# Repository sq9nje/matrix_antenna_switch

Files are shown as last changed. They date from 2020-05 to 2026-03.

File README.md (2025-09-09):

# 6x2 Matrix Antenna Switch

A complete antenna switching system that allows connecting two transceivers to up to 6 antennas with intelligent control and protection.

## Overview

This project implements a 6x2 matrix antenna switch system consisting of two main modules:

- **Relay Module**: High-power RF switching matrix with electromechanical relays
- **Interface Module**: ESP32-based control system with RS485 communication

The system provides flexible antenna routing while preventing simultaneous connection of both transceivers to the same antenna, ensuring equipment protection and operational safety.

## Key Features

### RF Performance
- **Power Handling**: Up to 1.5kW (full amateur license power)
- **Frequency Range**: DC to 50+ MHz with good performance
- **Protection**: Gas discharge tubes on all antenna ports for lightning/ESD protection
- **Isolation**: Decent port-to-port isolation
  - Better than 75dB below 10MHz
  - Better than 65dB below 30MHz
  - Better than 50dB below 50MHz
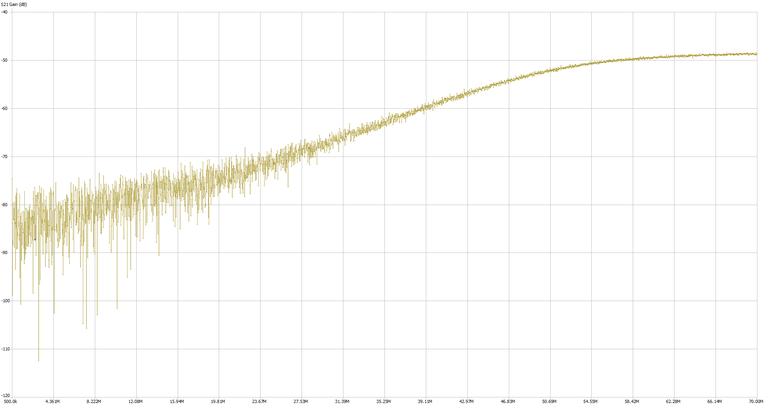
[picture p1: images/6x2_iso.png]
Isolation Performance RF Isolation Performance


### Control System
- **ESP32-based**: WiFi-enabled microcontroller with comprehensive firmware
- **Multiple Interfaces**: Web UI, REST API, WebSocket, and serial command control
- **Network Features**: mDNS discovery (`antenna.local`), OTA updates, WiFi management
- **Smart Features**: Antenna conflict prevention, single radio mode, persistent settings
- **RS485 Interface**: Reliable half-duplex communication with automatic direction detection
- **Expandability**: SAO (Simple Add-On) connector for future enhancements

### Design Features
- **Modular Architecture**: Separate relay and interface modules for flexibility
- **Three-Relay Configuration**: Prevents transceiver conflicts while maintaining isolation
- **Professional PCB Design**: Multi-layer boards with proper grounding and shielding
- **Easy Assembly**: Through-hole components for straightforward construction

## System Architecture

The complete system consists of:

1. **[Relay Module](relay_module/hardware/README.md)**:
   - 6 antenna sections, each with 3 relays
   - Allows connection to Radio 1, Radio 2, or 50Ω dummy load
   - Comprehensive protection circuitry

2. **[Interface Module](interface_module/hardware/README.md)**: Provides intelligent control and communication
   - ESP32 DevKit v1 for processing and connectivity
   - RS485 interface for remote control
   - Expansion connector for additional features

## Documentation

### Hardware Documentation
- **[Relay Module Hardware](relay_module/hardware/README.md)** - Complete RF switching matrix documentation
- **[Interface Module Hardware](interface_module/hardware/README.md)** - ESP32 control system hardware

### Firmware Documentation  
- **[Interface Module Firmware](interface_module/firmware/README.md)** - ESP32 firmware with web interface, REST API, and OTA updates

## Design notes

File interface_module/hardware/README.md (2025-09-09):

# Interface Module Hardware

This directory contains all hardware design files for the 6x2 Matrix Antenna Switch Interface Module, designed in KiCad.

## Overview

The interface module is the control hub for the 6x2 matrix antenna switch system, designed by SQ9NJE (Quirky Solutions). The main component of the interface module is an ESP32 DevKit v1 development board. The module is also equipped with a half-duplex RS485 interface with automatic transmission direction detection and a 5V voltage regulator.

Next to the control signal connector for connecting the relay module, there is an additional SAO (Simple Add-On) connector. This connector provides access to I2C bus signals, two GPIO pins, and 3.3V power supply with ground. In the future, it may be used to extend the hardware capabilities of the switch, such as adding a display, band decoder, etc.

**📋 [View Schematic (PDF)](interface_module.pdf)**

**🔧 [Interactive BOM](https://htmlpreview.github.io/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){:target="_blank"}**

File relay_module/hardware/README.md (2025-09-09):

# Relay Module Hardware

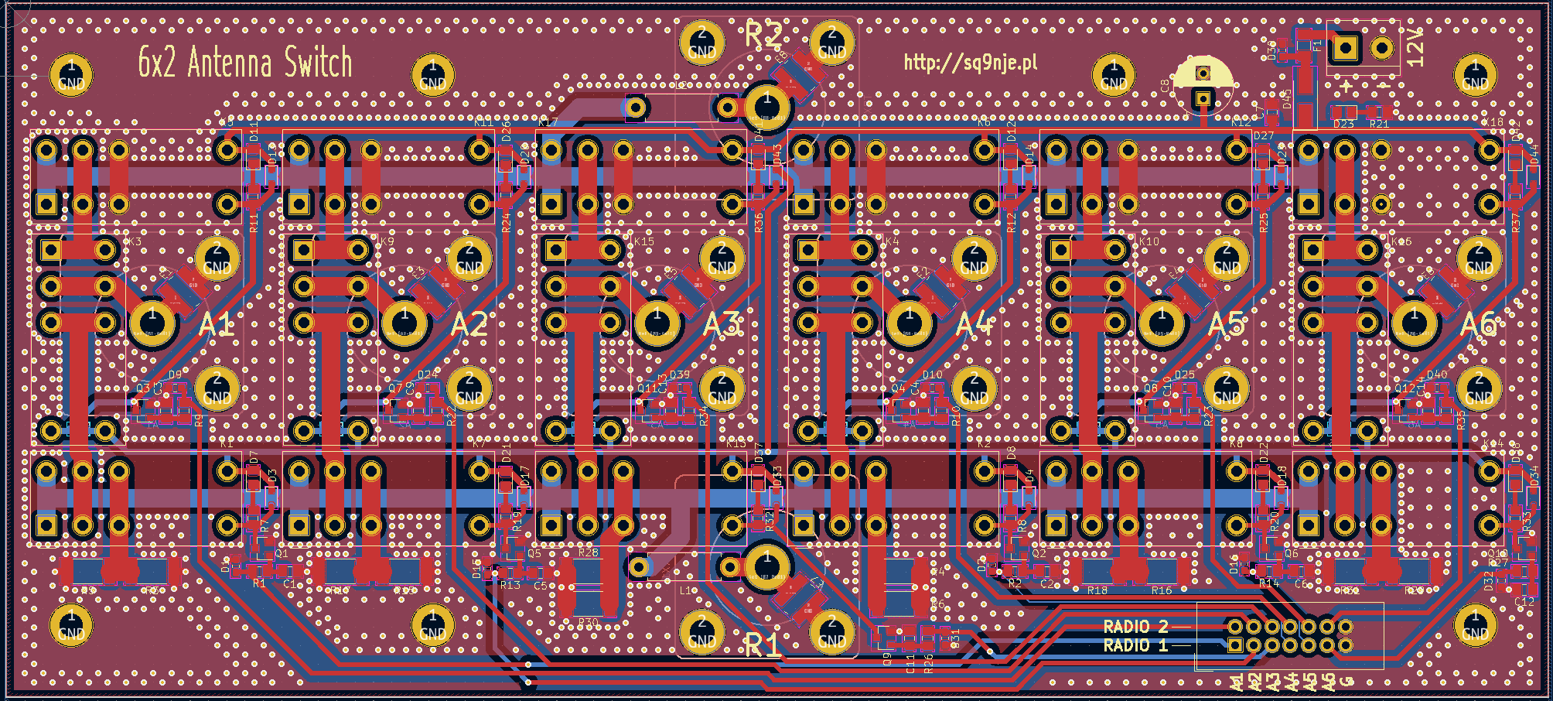
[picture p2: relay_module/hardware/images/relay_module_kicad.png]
Relay Module PCB Layout


This directory contains all hardware design files for the 6x2 Matrix Antenna Switch relay module, designed in KiCad.

## Overview

The relay module is a part of a 6x2 matrix antenna switch. It consists of six identical sections, one for each antenna. Each section allows connecting an antenna to Radio 1, Radio 2, or a 50-ohm dummy load (2W capacity). The design uses a popular three-relay configuration that prevents simultaneous connection of both transceivers to the same antenna while ensuring satisfactory isolation.

The relays are suitable for switching signals from transmitters at full amateur radio license power (1.5kW). All antenna ports are protected with gas discharge tubes (GDTs) to help protect radio inputs from high voltages generated during nearby lightning strikes or electrostatic charge buildup in antennas. However, the switch should not be considered a complete lightning protection solution.

**📋 [View Schematic (PDF)](images/relay_module.pdf)**

**🔧 [Interactive BOM](https://htmlpreview.github.io/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){:target="_blank"}**

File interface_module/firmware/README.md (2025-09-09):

# ESP32 6x2 Antenna Switch - Interface Module Firmware

Modern ESP32-based firmware for the 6x2 matrix antenna switch, providing comprehensive control through web interface, REST API, WebSocket, and serial commands with Over-The-Air (OTA) update capabilities.

## Overview

This firmware transforms the antenna switch into a smart, network-connected device that can be controlled remotely through multiple interfaces:

- **🌐 Web Interface**: Intuitive browser-based control panel
- **🔗 REST API**: HTTP endpoints for integration with external systems
- **⚡ WebSocket**: Real-time bidirectional communication
- **📟 Serial Commands**: Direct UART control for automation
- **🔄 OTA Updates**: Wireless firmware and filesystem updates
- **🏠 mDNS Discovery**: Automatic network discovery (`antenna.local`)

## Features

### Control Interfaces
- **Web UI**: Modern responsive interface at `http://antenna.local`
- **REST API**: 20+ endpoints for programmatic control
- **WebSocket**: Real-time state updates and control
- **Serial**: Simple text commands via USB or RS-485

### Smart Features
- **Antenna Swapping Prevention**: Automatic conflict resolution
- **Single Radio Mode**: Lock to one radio for simplex operation
- **Safety Interlocks**: Relay disconnect during firmware updates
- **Persistent Settings**: Configuration survives power cycles
- **Real-time Feedback**: Instant status updates across all interfaces

### Network & Updates
- **WiFi Manager**: Easy network configuration with fallback AP mode
- **mDNS**: Access via `antenna.local` hostname
- **OTA Updates**: Wireless firmware and web file updates
- **Dual Upload**: Maintains USB serial compatibility for development

## Hardware Requirements

- **ESP32 DevKit V1** (or compatible)
- **6x2 Antenna Switch Module** (relay control board)
- **5V Power Supply** (adequate for ESP32 + relays)

### Pin Assignments
```
Radio 1 Relays: GPIO 18, 5, 17, 16, 4, 2    (Antennas 1-6)
Radio 2 Relays: GPIO 15, 13, 12, 14, 27, 26 (Antennas 1-6)
Status LED:     GPIO 25
```

## Quick Start

### 1. Build and Flash
```bash
# Clone and setup
git clone <repository>
cd interface_module/firmware

# Build firmware
pio run -e esp32doit-devkit-v1

# Upload via USB
pio run -e esp32doit-devkit-v1 -t upload

# Upload web files
pio run -e esp32doit-devkit-v1 -t uploadfs
```

### 2. Initial Setup
1. **Connect to WiFi**: Device creates `AntennaSwitch-XXXX` AP for initial setup
2. **Configure Network**: Use WiFi Manager portal to connect to your network
3. **Access Interface**: Navigate to `http://antenna.local` or device IP

### 3. Basic Operation
- **Web Control**: Use browser interface for manual switching
- **API Integration**: Connect external software via REST API
- **Serial Control**: Send commands via USB serial at 115200 baud

## Documentation

### 📚 Complete API References
- **[REST & WebSocket API](REST_WebSocket_API.md)** - HTTP endpoints and real-time WebSocket communication
- **[Serial Commands](SERIAL_COMMANDS.md)** - UART command interface for automation and integration

### 🔧 Build & Deployment
- **[OTA Build Guide](OTA_BUILD_GUIDE.md)** - Firmware building, OTA updates, and deployment workflows

### 📋 Quick Reference Cards

#### Web Interface URLs
- **Main Control**: `http://antenna.local/`
- **Settings**: `http://antenna.local/settings`
- **System Status**: `http://antenna.local/status`
- **OTA Updates**: `http://antenna.local/ota`

#### Common API Endpoints
```bash
# Get current antenna state
curl http://antenna.local/api/state

# Switch Radio 1 to Antenna 3
curl -X POST http://antenna.local/api/antennas \\
  -H "Content-Type: application/json" \\
  -d '{"1":3}'

# Get system status
curl http://antenna.local/api/status
```

#### Serial Commands
```bash
set 1 3      # Switch Radio 1 to Antenna 3
get 1        # Get current antenna for Radio 1
?            # Device information
test         # Test all relays
```

## Architecture

### Core Components
- **`main.cpp`**: Application entry point and main loop
- **`antenna_hardware.cpp`**: Relay control and switching logic
- **`web_server.cpp`**: HTTP server and REST API endpoints
- **`websocket.cpp`**: Real-time WebSocket communication
- **`command_parser.cpp`**: Serial command processing
- **`wifi_manager.cpp`**: Network configuration and management

### Web Assets (`data/` directory)
- **`index.html`**: Main control interface
- **`settings.html`**: Configuration page
- **`status.html`**: System information display
- **`ota.html`**: Firmware update interface
- **`style.css`**: Responsive UI styling
- **`script.js`**: Client-side JavaScript logic

## Development

### Build Environments
```ini
# USB Development (default)
[env:esp32doit-devkit-v1]
upload_port = /dev/ttyUSB0

# Wireless OTA Updates
[env:esp32doit-devkit-v1-ota]
upload_protocol = espota
upload_port = antenna.local
```

### Dependencies
- **ESPAsyncWebServer**: HTTP server with async support
- **WebSocketsServer**: Real-time bidirectional communication
- **ArduinoJson**: JSON parsing and generation
- **WiFiManager**: Network configuration portal
- **ArduinoOTA**: Over-the-air update support

### Build Scripts
- **`build_ota.sh`**: Complete build with automatic file copying
- **`copy_ota_files.py`**: Manual file copying for OTA deployment
- **`build_version.py`**: Automatic versioning and timestamp injection

## Configuration

### WiFi Setup
1. **Initial Setup**: Device creates `AntennaSwitch-XXXX` access point
2. **Connect**: Join AP and navigate to `192.168.4.1`
3. **Configure**: Select your WiFi network and enter credentials
4. **Automatic**: Device connects to your network and starts mDNS

### Default Settings
- **Hostname**: `antenna` (accessible via `antenna.local`)
- **OTA Password**: `antenna123`
- **WebSocket Port**: `81`
- **Serial Baud**: `115200`

### Customization
- **Antenna Names**: Configure via web interface or API
- **Operation Modes**: Single radio mode, antenna swapping prevention
- **Network Settings**: Static IP, custom hostname via web settings

## Troubleshooting

### Common Issues
**Device Not Accessible:**
- Check WiFi connection and signal strength
- Try IP address instead of `antenna.local`
- Reset network settings via serial: `AT+RST`

**OTA Update Fails:**
- Verify file type (firmware vs SPIFFS)
- Check available flash space
- Ensure stable WiFi connection during upload

**Relays Not Switching:**
- Check power supply capacity (relays need adequate current)
- Verify pin connections against hardware documentation
- Use `test` serial command to verify hardware operation

### Debug Access
- **Serial Monitor**: Connect USB, open serial terminal at 115200 baud
- **System Status**: Check `/status` page for detailed system information
- **API Status**: Use `/api/status` endpoint for JSON system data

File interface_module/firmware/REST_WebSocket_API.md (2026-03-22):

# ESP32 Antenna Switch REST & WebSocket API

This document describes the REST and WebSocket API endpoints for the 6x2 ESP32 antenna switch interface module.

## Table of Contents

- [ESP32 Antenna Switch REST \& WebSocket API](#esp32-antenna-switch-rest--websocket-api)
  - [Table of Contents](#table-of-contents)
  - [Base URL \& Authentication](#base-url--authentication)
  - [Content Types](#content-types)
  - [Antenna Management](#antenna-management)
    - [Get All Antennas](#get-all-antennas)
    - [Update All Antennas](#update-all-antennas)
    - [Get Single Antenna Info](#get-single-antenna-info)
    - [Update Single Antenna](#update-single-antenna)
  - [Switch State](#switch-state)
    - [Get Current State](#get-current-state)
  - [Configuration](#configuration)
    - [Get Hostname](#get-hostname)
    - [Update Hostname](#update-hostname)
    - [Get Operation Mode](#get-operation-mode)
    - [Update Operation Mode](#update-operation-mode)
  - [Device Status](#device-status)
    - [Get System Status](#get-system-status)
  - [Settings Backup & Restore](#settings-backup--restore)
    - [Export Settings](#export-settings)
    - [Import Settings](#import-settings)
  - [System Administration](#system-administration)
    - [Reboot Device](#reboot-device)
    - [Reset Network Settings](#reset-network-settings)
  - [OTA Updates](#ota-updates)
    - [Upload Firmware/SPIFFS](#upload-firmwarespiffs)
  - [WebSocket API](#websocket-api)
    - [Connection](#connection)
    - [Client → Server Messages](#client--server-messages)
      - [Switch Antenna](#switch-antenna)
    - [Server → Client Messages](#server--client-messages)
      - [Current State Update](#current-state-update)
      - [Antenna Names Update](#antenna-names-update)
      - [OTA Progress Updates](#ota-progress-updates)
    - [Connection Events](#connection-events)
      - [New Client Connection](#new-client-connection)
      - [Client Disconnection](#client-disconnection)
  - [Error Codes](#error-codes)
  - [OTRSP (SO2R Protocol)](#otrsp-so2r-protocol)
    - [Get OTRSP Status](#get-otrsp-status)
    - [Enable/Disable OTRSP](#enabledisable-otrsp)
  - [Examples](#examples)
    - [Switch Radio 1 to Antenna 3 via WebSocket](#switch-radio-1-to-antenna-3-via-websocket)
    - [Monitor Real-time State Changes](#monitor-real-time-state-changes)
    - [Get Device IP and Connection Info](#get-device-ip-and-connection-info)
    - [Update Antennas](#update-antennas)

---

## Base URL & Authentication

**Base URL:**
- Default: `http://antenna.local` (via mDNS)
- Alternative: `http://<device_ip>`
- WebSocket: `ws://<host>:81/`

**Authentication:**
No authentication required for current implementation.

## Content Types
- **Request**: `application/json` for POST/PUT bodies
- **Response**: `application/json` for data endpoints, `text/plain` for status messages

---

## Antenna Management

### Get All Antennas
```http
GET /api/antennas
```
**Response:**
```json
[
  {"name": "Dipole", "bands": ["20m", "15m"]},
  {"name": "Yagi", "bands": ["10m"]},
  {"name": "Loop", "bands": ["80m", "40m"]},
  {"name": "Vertical", "bands": ["160m", "80m", "40m", "20m"]},
  {"name": "Antenna 5", "bands": []},
  {"name": "Antenna 6", "bands": []}
]
```

### Update All Antennas
```http
POST /api/antennas
Content-Type: application/json

{
  "0": {"name": "New Name 1", "bands": ["20m", "15m"]},
  "1": {"name": "New Name 2", "bands": ["80m"]},
  "2": {"name": "New Name 3", "bands": []}
}
```
**Response:** `200 OK`

**Backward Compatibility:** Plain string values are also accepted for name-only updates:
```json
{"0": "New Name 1", "1": "New Name 2"}
```

### Get Single Antenna Info
```http
GET /api/antenna/{index}
```
**Parameters:**
- `index`: Antenna index (0-5)

**Response:**
```json
{
  "index": 0,
  "name": "Dipole",
  "bands": ["20m", "15m"]
}
```

### Update Single Antenna
```http
PUT /api/antenna/{index}
Content-Type: application/json

{
  "name": "New Antenna Name",
  "bands": ["20m", "40m"]
}
```
Both `name` and `bands` fields are optional; only provided fields are updated.

**Response:** `200 OK`

---

## Switch State

### Get Current State
```http
GET /api/state
```
**Response:**
```json
{
  "radio1": 1,
  "radio2": 3
}
```
**Note:** Values 0 = disconnected, 1-6 = antenna index

---

## Configuration

### Get Hostname
```http
GET /api/hostname
```
**Response:**
```json
{
  "hostname": "antenna"
}
```

### Update Hostname
```http
POST /api/hostname
Content-Type: application/json

{
  "hostname": "my-antenna-switch"
}
```
**Response:** `200 OK - Restart required for changes to take effect`

### Get Operation Mode
```http
GET /api/operation-mode
```
**Response:**
```json
{
  "antennaSwapping": true,
  "singleRadioMode": false
}
```

### Update Operation Mode
```http
POST /api/operation-mode
Content-Type: application/json

{
  "antennaSwapping": false,
  "singleRadioMode": true
}
```
**Response:** `200 OK`

---

## Device Status

### Get System Status
```http
GET /api/status
```
**Response:**
```json
{
  "ssid": "MyWiFi",
  "ip": "192.168.1.100",
  "gateway": "192.168.1.1",
  "subnet": "255.255.255.0",
  "dns": "192.168.1.1",
  "rssi": -45,
  "macAddress": "AA:BB:CC:DD:EE:FF",
  "hostname": "antenna",
  "firmwareVersion": "1.0.0",
  "buildTime": "20240909_143022",
  "chipModel": "ESP32-D0WD-V3",
  "chipRevision": 3,
  "cpuFreqMHz": 240,
  "freeHeap": 123456,
  "totalHeap": 327680,
  "uptime": 3600,
  "currentRadio1": 1,
  "currentRadio2": 0
}
```

---

## Settings Backup & Restore

### Export Settings
```http
GET /api/settings/export
```
Downloads all device settings as a JSON file.

**Response:**
```json
{
  "mdnsHostname": "antenna",
  "antennaSwapping": false,
  "singleRadioMode": false,
  "otrspEnabled": true,
  "otrspSerialEnabled": false,
  "antennas": [
    {"name": "Dipole", "bands": ["20m", "15m"]},
    {"name": "Yagi", "bands": ["10m"]},
    {"name": "Loop", "bands": ["80m", "40m"]},
    {"name": "Vertical", "bands": ["160m", "80m", "40m", "20m"]},
    {"name": "Antenna 5", "bands": []},
    {"name": "Antenna 6", "bands": []}
  ]
}
```
**Headers:** `Content-Disposition: attachment; filename="settings.json"`

### Import Settings
```http
POST /api/settings/import
Content-Type: application/json

{
  "mdnsHostname": "antenna",
  "antennaSwapping": true,
  "singleRadioMode": false,
  "otrspEnabled": true,
  "otrspSerialEnabled": false,
  "antennas": [
    {"name": "Dipole", "bands": ["20m", "15m"]},
    {"name": "Yagi", "bands": ["10m"]},
    {"name": "Loop", "bands": ["80m", "40m"]},
    {"name": "Vertical", "bands": ["160m", "80m", "40m", "20m"]},
    {"name": "Antenna 5", "bands": []},
    {"name": "Antenna 6", "bands": []}
  ]
}
```
Restores settings from a previously exported JSON file. All fields are optional; only provided fields are updated.

**Backward Compatibility:** The old format with separate `antennaNames` and `antennaBands` arrays is also accepted for import.

**Response:** `200 Settings imported successfully`

**Errors:**
- `400 Invalid JSON` — Request body is not valid JSON

**Side Effects:**
- Settings are saved to SPIFFS
- WebSocket state and antenna name updates are broadcast to all connected clients

---

## System Administration

### Reboot Device
```http
POST /api/reboot
```
**Response:** `200 Device rebooting...`

### Reset Network Settings
```http
POST /api/reset-network
```
**Response:** `200 Network settings reset. Device will reboot...`

---

## OTA Updates

### Upload Firmware/SPIFFS
```http
POST /api/update
Content-Type: multipart/form-data

form-data: firmware=<binary_file>
```
**File Type Detection:**
- Files containing "firmware" → Firmware update
- Files containing "spiffs" → SPIFFS/filesystem update
- Generic `.bin` files → Assumed firmware

**Response:** `200 Update Success` or `200 Update Failed`

**Progress Updates:** Real-time progress sent via WebSocket:
```json
{
  "type": "ota",
  "status": "progress",
  "progress": 75,
  "message": ""
}
```

---

## WebSocket API

### Connection
Connect to `ws://<host>:81/` for real-time bidirectional communication.

### Client → Server Messages

#### Switch Antenna
```json
{
  "type": "select",
  "radio": 1,
  "antenna": 3
}
```
**Parameters:**
- `radio`: Radio number (1 or 2)
- `antenna`: Antenna number (1-6, or 0 to disconnect)

### Server → Client Messages

#### Current State Update
Sent automatically when antenna state changes or client connects:
```json
{
  "type": "state",
  "radio1": 2,
  "radio2": 0,
  "singleRadioMode": false
}
```
**Fields:**
- `radio1`/`radio2`: Current antenna (0 = disconnected, 1-6 = antenna number)
- `singleRadioMode`: Whether single radio mode is enabled

#### Antenna Names Update
Sent when antenna names or bands are changed, or client connects:
```json
{
  "type": "antennaNames",
  "antennas": [
    {"name": "Dipole", "bands": ["20m", "15m"]},
    {"name": "Yagi", "bands": ["10m"]},
    {"name": "Loop", "bands": ["80m", "40m"]},
    {"name": "Vertical", "bands": []},
    {"name": "Antenna 5", "bands": []},
    {"name": "Antenna 6", "bands": []}
  ]
}
```

#### OTA Progress Updates
Real-time firmware/SPIFFS upload progress:
```json
{
  "type": "ota",
  "status": "starting|progress|complete|error",
  "progress": 75,
  "message": "Status message"
}
```
**Status Values:**
- `starting`: Upload beginning
- `progress`: Upload in progress (see `progress` field 0-100)
- `complete`: Upload successful, device restarting
- `error`: Upload failed (see `message` for details)

### Connection Events

#### New Client Connection
When a client connects:
1. Server automatically sends current `state` message
2. Server automatically sends current `antennaNames` message

#### Client Disconnection
Server logs disconnection but takes no other action.

---

## OTRSP (SO2R Protocol)

The device supports the [Open Two Radio Switching Protocol (OTRSP)](https://www.k1xm.org/OTRSP/) for integration with contest logging software such as N1MM+, WriteLog, and Win-Test. OTRSP is available over TCP (port 12060) and optionally on the RS-485 serial port.

### Get OTRSP Status
```http
GET /api/otrsp/status
```
**Response:**
```json
{
  "enabled": true,
  "serialEnabled": false,
  "tcpPort": 12060,
  "clientConnected": true,
  "txFocus": 1,
  "rxFocus": "1",
  "band1": "14.0",
  "band2": "0",
  "mode1": "U",
  "mode2": "0"
}
```
**Fields:**
- `enabled`: Whether the OTRSP TCP server is active
- `serialEnabled`: Whether OTRSP is enabled on the RS-485 serial port
- `tcpPort`: TCP port number (always 12060)
- `clientConnected`: Whether a TCP client is currently connected
- `txFocus`: Which radio has transmit focus (1 or 2)
- `rxFocus`: Receive focus mode ("1", "2", "1S", "2S", "1R", "2R")
- `band1`/`band2`: Band frequency reported by logging software per radio
- `mode1`/`mode2`: Operating mode per radio (C=CW, U=USB, L=LSB, R=RTTY, F=FM, A=AM, X=other, 0=not set)

### Enable/Disable OTRSP
```http
POST /api/otrsp/enable
Content-Type: application/json

{
  "enabled": true,
  "serialEnabled": false
}
```
Both fields are optional; only provided fields are updated. A device restart is required for TCP server changes to take effect.

**Response:** `200 OK - Restart required for TCP changes to take effect`

---

## Error Codes

- `200`: Success
- `400`: Bad Request (invalid parameters/JSON)
- `404`: Not Found (invalid endpoint/antenna index)
- `500`: Internal Server Error

## Examples

### Switch Radio 1 to Antenna 3 via WebSocket
```javascript
const ws = new WebSocket('ws://antenna.local:81/');
ws.onopen = function() {
  ws.send(JSON.stringify({
    type: "select",
    radio: 1,
    antenna: 3
  }));
};
```

### Monitor Real-time State Changes
```javascript
const ws = new WebSocket('ws://antenna.local:81/');
ws.onmessage = function(event) {
  const data = JSON.parse(event.data);
  if (data.type === 'state') {
    console.log(`Radio 1: ${data.radio1}, Radio 2: ${data.radio2}`);
  } else if (data.type === 'antennaNames') {
    console.log('Antennas updated:', data.antennas);
  }
};
```

### Get Device IP and Connection Info
```bash
curl http://antenna.local/api/status | jq '.ip, .ssid, .rssi'
```

### Update Antennas
```bash
curl -X POST http://antenna.local/api/antennas \
  -H "Content-Type: application/json" \
  -d '{"0":{"name":"Dipole","bands":["20m","15m"]},"1":{"name":"Yagi","bands":["10m"]}}'
```

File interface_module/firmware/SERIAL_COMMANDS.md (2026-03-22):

# ESP32 Antenna Switch Serial Commands

This document describes the serial command interface for the 6x2 ESP32 antenna switch interface module.

## Table of Contents

- [Connection Setup](#connection-setup)
- [Command Format](#command-format)
- [Available Commands](#available-commands)
  - [Switch Antenna](#switch-antenna-set)
  - [Get Current Antenna](#get-current-antenna-get)
  - [Device Information](#device-information-)
  - [LED Blink Test](#led-blink-test-blink)
  - [Full System Test](#full-system-test-test)
- [Response Codes](#response-codes)
- [Examples](#examples)
- [Troubleshooting](#troubleshooting)

---

## Connection Setup

### Serial Ports
The device supports command input on two serial interfaces:

- **UART0 (USB Serial)**: Primary interface for debugging and development
  - Baud rate: 115200 (default)
  - Data bits: 8, Parity: None, Stop bits: 1
  - Connect via USB cable to computer

- **UART2 (RS-485/External)**: Secondary interface for remote control
  - Baud rate: 9600, Data bits: 8, Parity: None, Stop bits: 1
  - Responses are sent to UART0 (USB) for debugging
  - Can be switched to OTRSP protocol mode (see [OTRSP Mode](#otrsp-mode-on-uart2))

### Connection Examples
```bash
# Linux/macOS - USB serial
screen /dev/ttyUSB0 115200
# or
minicom -D /dev/ttyUSB0 -b 115200

# Windows - USB serial  
PuTTY - Serial, COM3, 115200

# Arduino IDE Serial Monitor
Tools → Serial Monitor, 115200 baud
```

---

## Command Format

### Structure
```
<command> [parameters]<CR><LF>
```

### Rules
- Commands are **case-insensitive** (automatically converted to lowercase)
- Parameters are separated by **single spaces**
- Commands must end with **carriage return (CR)** and/or **line feed (LF)**
- Maximum command length: **31 characters** (including parameters)
- Invalid or incomplete commands are ignored silently

---

## Available Commands

### Switch Antenna: `set`
Switch a radio to a specific antenna.

**Syntax:**
```
set <radio> <antenna>
```

**Parameters:**
- `radio`: Radio number (1 or 2)
- `antenna`: Antenna number (1-6, or 0 to disconnect)

**Responses:**
- `+OK`: Antenna switched successfully
- `!ERR`: Invalid parameters (radio/antenna out of range)
- `!BUSY`: Single radio mode enabled and trying to switch radio 2

**Examples:**
```bash
set 1 3      # Switch Radio 1 to Antenna 3
set 2 0      # Disconnect Radio 2
set 1 6      # Switch Radio 1 to Antenna 6
set 2 1      # Switch Radio 2 to Antenna 1
```

### Get Current Antenna: `get`
Query the current antenna for a specific radio.

**Syntax:**
```
get <radio>
```

**Parameters:**
- `radio`: Radio number (1 or 2)

**Response:**
- `0`: Radio disconnected
- `1-6`: Antenna number currently connected

**Examples:**
```bash
get 1        # Returns: 3 (if Radio 1 is on Antenna 3)
get 2        # Returns: 0 (if Radio 2 is disconnected)
```

### Device Information: `?`
Get device identification information.

**Syntax:**
```
?
```

**Response:**
```
6x2 Antenna Switch SQ9NJE
```

### LED Blink Test: `blink`
Blink the status LED for testing/identification purposes.

**Syntax:**
```
blink <count>
```

**Parameters:**
- `count`: Number of blinks (1-255)

**Examples:**
```bash
blink 3      # Blink LED 3 times
blink 10     # Blink LED 10 times
```

### Full System Test: `test`
Perform a complete relay test sequence.

**Syntax:**
```
test
```

**Behavior:**
1. Cycles through all antennas on Radio 1 (6→5→4→3→2→1→0)
2. Cycles through all antennas on Radio 2 (6→5→4→3→2→1→0)
3. Each step has 100ms delay
4. Total test time: ~1.4 seconds

**Use Cases:**
- Verify all relays are working
- Audio/visual confirmation of relay operation
- Factory testing and troubleshooting

---

## Response Codes

| Code | Meaning | Description |
|---|---|---|
| `+OK` | Success | Command executed successfully |
| `!ERR` | Error | Invalid parameters or command failed |
| `!BUSY` | Busy/Blocked | Operation blocked (e.g., single radio mode) |
| `0-6` | Status | Current antenna number (0=disconnected) |

---

## Examples

### Basic Antenna Switching
```bash
# Check current state
get 1          # Returns: 0 (disconnected)
get 2          # Returns: 0 (disconnected)

# Switch antennas
set 1 2        # Response: +OK
get 1          # Returns: 2

set 2 5        # Response: +OK  
get 2          # Returns: 5

# Disconnect radio
set 1 0        # Response: +OK
get 1          # Returns: 0
```

### Device Testing Sequence
```bash
# Identify device
?              # Returns: 6x2 Antenna Switch SQ9NJE

# Test LED
blink 5        # LED blinks 5 times

# Test all relays
test           # All relays cycle through sequence

# Manual relay verification  
set 1 1        # Switch to antenna 1
set 1 2        # Switch to antenna 2
set 1 3        # Switch to antenna 3
# ... continue testing each antenna
```

### Error Handling
```bash
# Invalid radio number
set 3 1        # Response: !ERR

# Invalid antenna number  
set 1 7        # Response: !ERR

# Single radio mode blocking
set 2 1        # Response: !BUSY (if single radio mode enabled)
```

### Arduino/ESP32 Integration
```cpp
// Send command via Serial
Serial.println("set 1 3");
delay(100);

// Read response
if (Serial.available()) {
  String response = Serial.readString();
  if (response.indexOf("+OK") >= 0) {
    // Success
  } else if (response.indexOf("!ERR") >= 0) {
    // Error
  }
}
```

---

## Troubleshooting

### Common Issues

**No Response to Commands:**
- Check baud rate (should be 115200)
- Verify line endings (CR/LF required)
- Ensure command length < 32 characters
- Try device info command: `?`

**Commands Ignored:**
- Check for proper command termination (Enter key)
- Verify parameters are within valid ranges
- Commands are processed only when complete line received

**Relay Not Switching:**
- Use `test` command to verify hardware
- Check power supply (relays need adequate current)
- Verify connections with multimeter
- Try `blink` command to confirm device is responding

**Error Responses:**
- `!ERR`: Check parameter ranges (radio: 1-2, antenna: 0-6)
- `!BUSY`: Check if single radio mode is enabled via web interface

### Debug Information
All commands sent to UART2 (RS-485) will show responses on UART0 (USB) for debugging purposes.

### Serial Monitor Settings
- **Baud Rate**: 115200
- **Line Ending**: Both NL & CR (or just CR)
- **Local Echo**: Enabled (helpful for command verification)

---

## Integration Notes

### RS-485 Communication
- UART2 is intended for RS-485 remote control
- Use proper RS-485 transceiver circuit
- Responses are echoed to USB serial for debugging
- Implement proper bus arbitration for multi-drop networks

### Automation Scripts
The simple command structure makes it easy to integrate with:
- Shell scripts (`echo "set 1 3" > /dev/ttyUSB0`)
- Python serial libraries
- Ham radio logging software
- Contest automation systems
- Microcontroller projects

### Command Buffering
- Input buffer size: 32 characters
- Commands are processed line-by-line
- Partial commands are held until CR/LF received
- Buffer overflow protection (excess characters ignored)

---

## OTRSP Mode on UART2

When OTRSP serial mode is enabled in settings, UART2 (RS-485) switches from the native command protocol to the [Open Two Radio Switching Protocol (OTRSP)](https://www.k1xm.org/OTRSP/) v0.9.

### Serial Parameters
- **Baud rate**: 9600
- **Data bits**: 8, **Parity**: None, **Stop bits**: 1

### Protocol Format
OTRSP uses a different command format than the native protocol:
- Commands are terminated by **carriage return only** (`\r`, 0x0D)
- No space delimiters — keyword, item, and value are concatenated
- Commands are **case-sensitive** (no automatic lowercase conversion)
- Query commands are prefixed with `?`
- Unknown query commands are echoed back; unknown set commands are silently ignored

### Supported OTRSP Commands

| Command | Example | Description |
|---|---|---|
| `TX{n}` | `TX1\r` | Set transmit focus to radio n (1 or 2) |
| `RX{n}` | `RX1\r` | Set receive focus (1, 2, 1S, 2S, 1R, 2R) |
| `AUX{x}{n}` | `AUX13\r` | Set antenna for radio x to antenna n (0=disconnect, 1-6) |
| `BAND{x}{freq}` | `BAND114.0\r` | Report band frequency for radio x |
| `MODE{x}{m}` | `MODE1U\r` | Report mode for radio x (C/U/L/R/F/A/X) |
| `NAME{text}` | `NAME...\r` | Set device name (ignored) |
| `FW{ver}` | `FW...\r` | Set firmware version (ignored) |
| `?` | `?\r` | Ping — device responds `?\r` |
| `?TX` | `?TX\r` | Query transmit focus — responds e.g. `TX1\r` |
| `?RX` | `?RX\r` | Query receive focus — responds e.g. `RX1\r` |
| `?AUX{x}` | `?AUX1\r` | Query antenna for radio x — responds e.g. `AUX13\r` |
| `?NAME` | `?NAME\r` | Query device name — responds `NAME6x2 Antenna Switch SQ9NJE\r` |
| `?FW` | `?FW\r` | Query firmware version — responds `FW1.0.0\r` |

### Antenna Selection via AUX

The AUX command is the primary mechanism for antenna control from contest logging software:
- `AUX1` controls **Radio 1** antenna (maps to `selectAntenna(0, n)`)
- `AUX2` controls **Radio 2** antenna (maps to `selectAntenna(1, n)`)
- Value `0` disconnects the radio, values `1-6` select the corresponding antenna
- Values greater than 6 are ignored

### Enabling OTRSP Serial Mode

Enable via the web settings page or the REST API:
```bash
curl -X POST http://antenna.local/api/otrsp/enable \
  -H "Content-Type: application/json" \
  -d '{"serialEnabled": true}'
```

When OTRSP serial mode is active on UART2, the native serial commands (`set`, `get`, `?`, `test`, `blink`) are **not available** on that port. Native commands remain available on UART0 (USB).

### OTRSP over TCP

OTRSP is also available over TCP on port **12060** when enabled. This is the recommended connection method for N1MM+ and other logging software. See `REST_WebSocket_API.md` for configuration details.

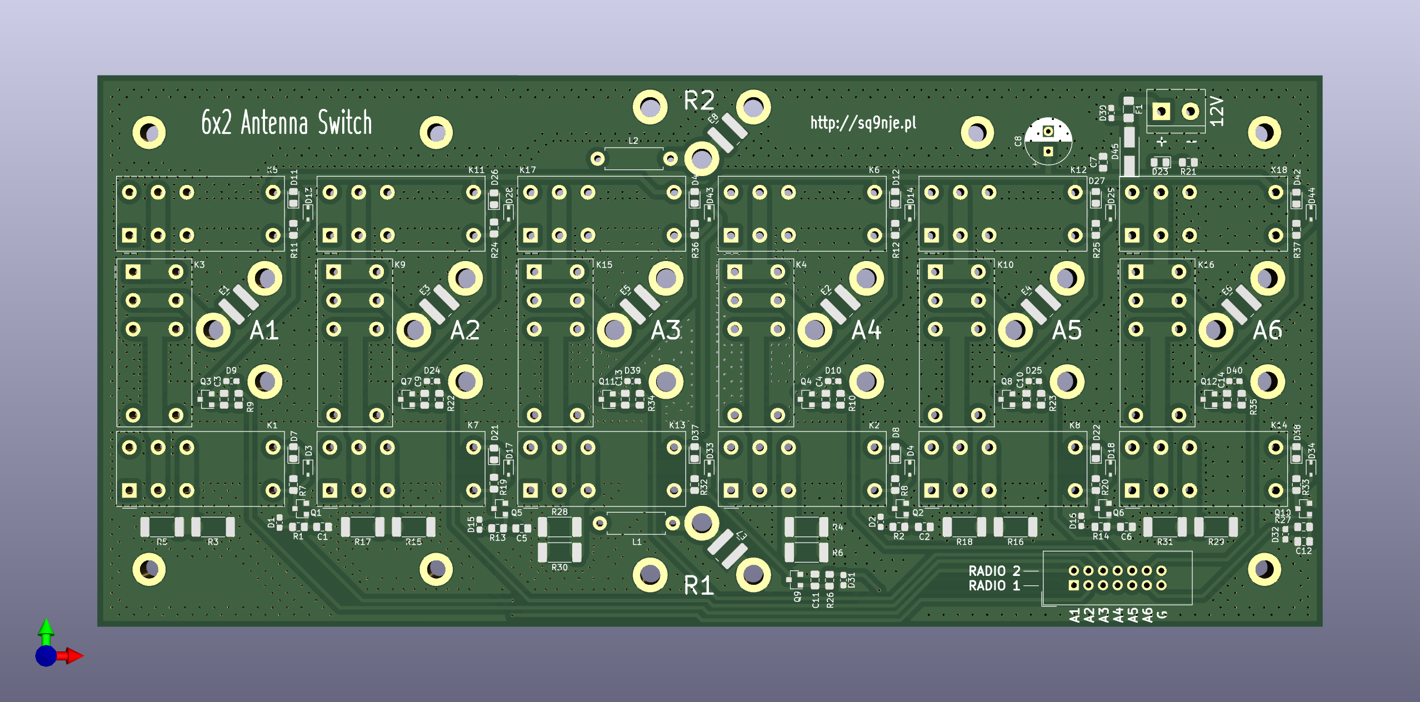
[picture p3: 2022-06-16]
relay_module/hardware/images/relay_module.png

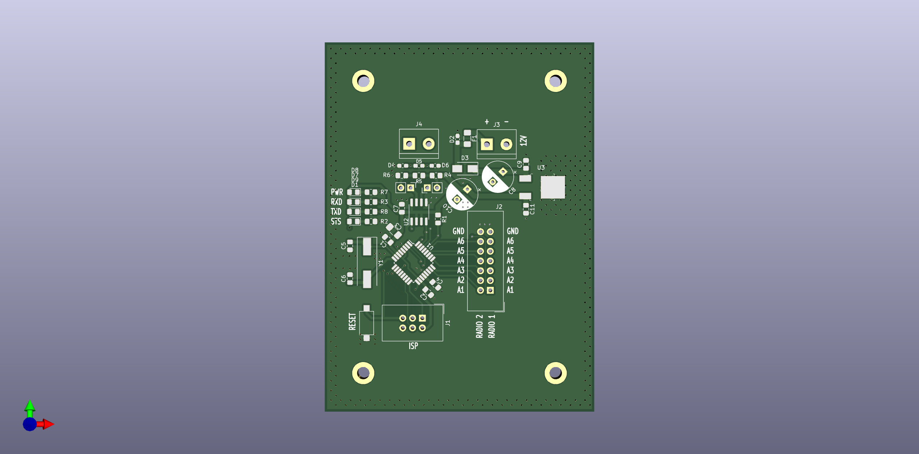
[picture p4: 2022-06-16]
images/antenna_switch_comms.png

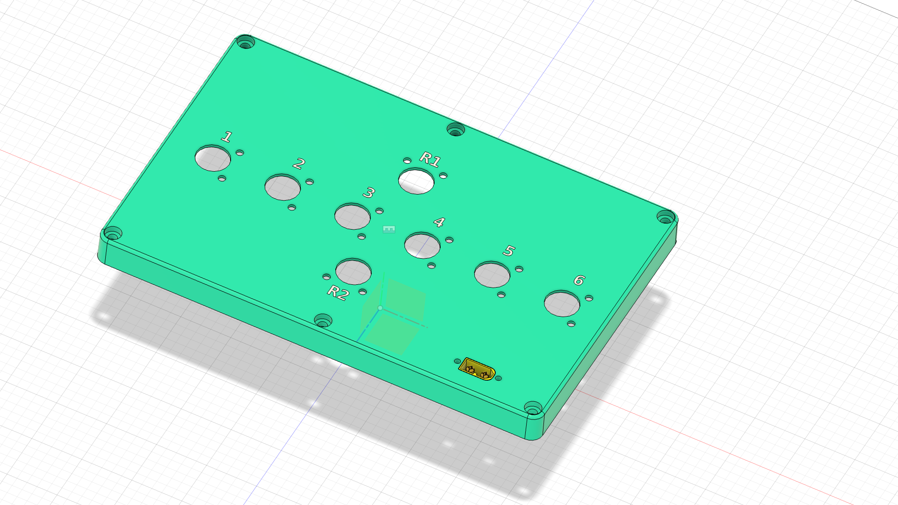
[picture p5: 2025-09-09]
enclosure/antenna_switch_enclosure_top.png

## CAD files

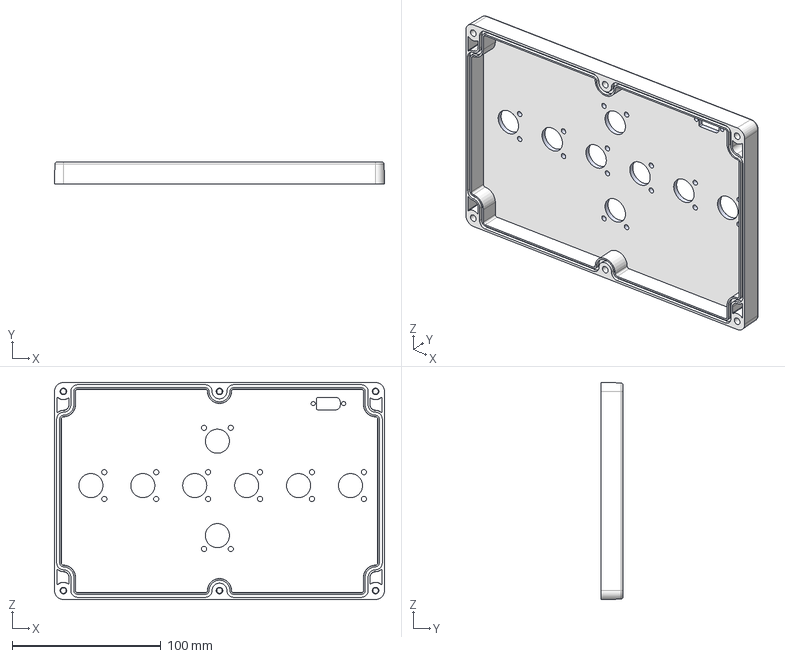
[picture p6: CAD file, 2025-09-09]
enclosure/antenna_switch_enclosure_top.step
222.0 x 15.0 x 146.0 mm

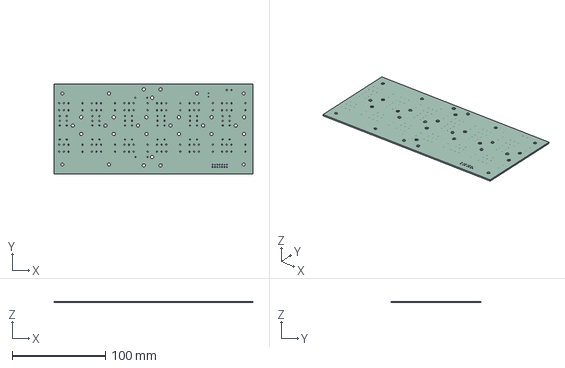
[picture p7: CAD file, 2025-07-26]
relay_module/hardware/relay_module.step
213.3 x 96.0 x 1.51 mm

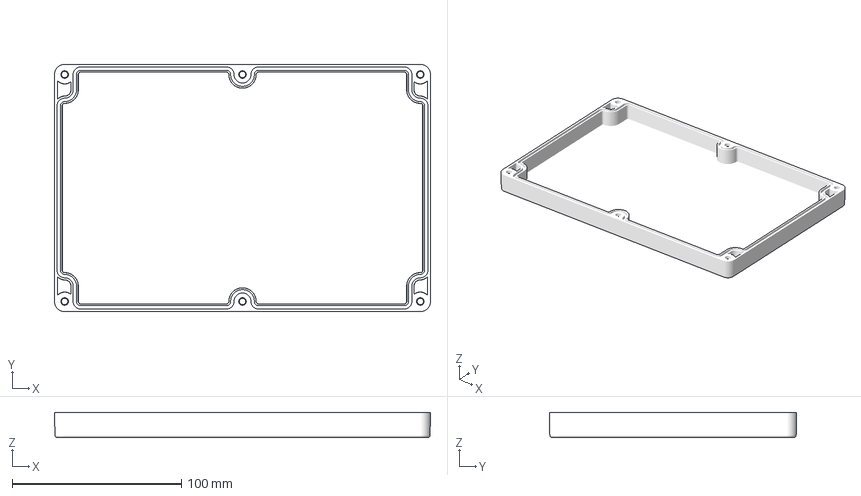
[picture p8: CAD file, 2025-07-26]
enclosure/G218_cover.3mf
222.0 x 146.0 x 15.0 mm

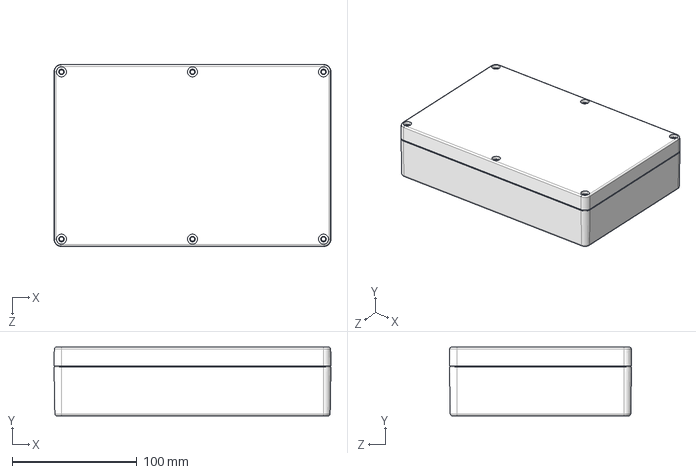
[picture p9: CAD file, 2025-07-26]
enclosure/User Library-G218-G317-REV-F.step
222.0 x 55.0 x 146.0 mm

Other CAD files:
enclosure/User Library-G218-G317-REV-F.SLDPRT
enclosure/antenna_switch_enclosure_top.3mf

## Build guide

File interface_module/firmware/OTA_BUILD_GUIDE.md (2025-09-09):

# OTA Build Guide for ESP32 Antenna Switch

This guide explains how to build firmware and filesystem images for Over-The-Air (OTA) updates.

## Quick Start

### Option 1: Manual Build + Copy (Recommended)
```bash
# Build firmware
pio run -e esp32doit-devkit-v1

# Build filesystem (optional)
pio run -e esp32doit-devkit-v1 --target buildfs

# Copy files for OTA upload
python3 copy_ota_files.py
```

### Option 2: Use the Build Script
```bash
./build_ota.sh
```

### Option 3: Individual Commands
```bash
# Build firmware only
pio run -e esp32doit-devkit-v1

# Build filesystem only  
pio run -e esp32doit-devkit-v1 --target buildfs

# Copy to OTA directory when ready
python3 copy_ota_files.py
```

## Output Files

After building, you'll find these files in the `.pio/build/esp32doit-devkit-v1/` directory:

- **`firmware.bin`** - Main application firmware
- **`spiffs.bin`** - Web interface and configuration files

## Using OTA Files

### Web Interface Method
1. Connect to your antenna switch web interface
2. Go to Settings → "Firmware Update (OTA)"
3. Upload the appropriate `.bin` file:
   - Use `firmware.bin` for firmware updates
   - Use `spiffs.bin` to update web files

### PlatformIO Upload Methods
```bash
# Upload firmware over USB serial (default)
pio run -e esp32doit-devkit-v1 -t upload

# Upload filesystem over USB serial
pio run -e esp32doit-devkit-v1 -t uploadfs

# Upload firmware over WiFi (OTA)
pio run -e esp32doit-devkit-v1-ota -t upload

# Upload filesystem over WiFi (OTA)
pio run -e esp32doit-devkit-v1-ota -t uploadfs
```

## Build Script Features

The `build_ota.sh` script provides:

- ✅ Automatic build of both firmware and filesystem
- 📦 Timestamped filenames for version tracking
- 🔗 Latest symlinks for easy access
- 📊 File size information
- ❌ Error checking and validation

## File Management

Due to PlatformIO post-build hook limitations, files are **not** automatically copied. Instead, use the manual copy approach:

### Standard Workflow
1. **Build your project** using any method (CLI, VSCode, etc.)
2. **Copy files** using: `python3 copy_ota_files.py`
3. **Upload via web interface** at `http://antenna.local/ota`

### Copy Script Features

The `copy_ota_files.py` script provides:

- 📁 Creates `ota_builds/` directory automatically
- 📦 Copies both firmware and SPIFFS files with timestamps
- 🏷️ Creates timestamped filenames: `antenna_switch_firmware_20240909_143022.bin`
- 🔗 Maintains `firmware_latest.bin` and `spiffs_latest.bin` links
- 📊 Shows file sizes and upload instructions
- ✅ Works with any build method (CLI, VSCode, Arduino IDE)

### Build + Copy Examples

```bash
# Standard workflow
pio run -e esp32doit-devkit-v1          # Build firmware
python3 copy_ota_files.py               # Copy for OTA

# With filesystem
pio run -e esp32doit-devkit-v1 --target buildfs  # Build SPIFFS
python3 copy_ota_files.py                        # Copy both files

# Using build script (does both)
./build_ota.sh
```

## Build Outputs

Files are created in the `ota_builds/` directory:

```
ota_builds/
├── antenna_switch_firmware_20240909_143022.bin
├── antenna_switch_spiffs_20240909_143022.bin
├── firmware_latest.bin -> antenna_switch_firmware_20240909_143022.bin
└── spiffs_latest.bin -> antenna_switch_spiffs_20240909_143022.bin
```

## Safety Notes

⚠️ **Important**: During OTA updates:
- All antenna relays are automatically disconnected
- Don't power off the device during updates
- Web interface shows real-time progress
- Device automatically restarts after successful update

## Troubleshooting

### Build Fails
- Check PlatformIO installation: `pio --version`
- Clean build: `pio run --target clean`
- Update dependencies: `pio pkg update`

### OTA Upload Fails
- Verify device is connected to WiFi
- Check mDNS hostname (default: `antenna.local`)
- Ensure OTA password is correct (`antenna123`)
- Try using IP address instead of hostname

### File Too Large
- Check available flash space: ESP32 has ~1.2MB for firmware
- SPIFFS partition size is defined in partition scheme
- Consider optimizing build flags for size

## Advanced Configuration

### Partition Scheme
The default partition scheme allocates:
- ~1.2MB for firmware
- ~1.5MB for SPIFFS
- Remaining for system use

### OTA Password
Default password is `antenna123`. To change:
1. Edit `main.cpp` line containing `setPassword`
2. Update `platformio.ini` upload flags
3. Rebuild and upload

## Version Information

The build system automatically adds:
- Build timestamp (format: YYYYMMDD_HHMMSS)
- Firmware version (currently 1.0.0)
- These are displayed on the device status page at `/status`

### Viewing Version Information
- **Web Interface**: Go to `/status` to see firmware version and build time
- **Serial Output**: Version info is displayed during boot
- **API**: Available via `/api/status` endpoint

## Integration with CI/CD

The build script can be integrated into automated workflows:

```bash
#!/bin/bash
# CI/CD example
cd firmware/
./build_ota.sh
if [ $? -eq 0 ]; then
    echo "Build successful, uploading artifacts..."
    # Upload to artifact storage
fi
```

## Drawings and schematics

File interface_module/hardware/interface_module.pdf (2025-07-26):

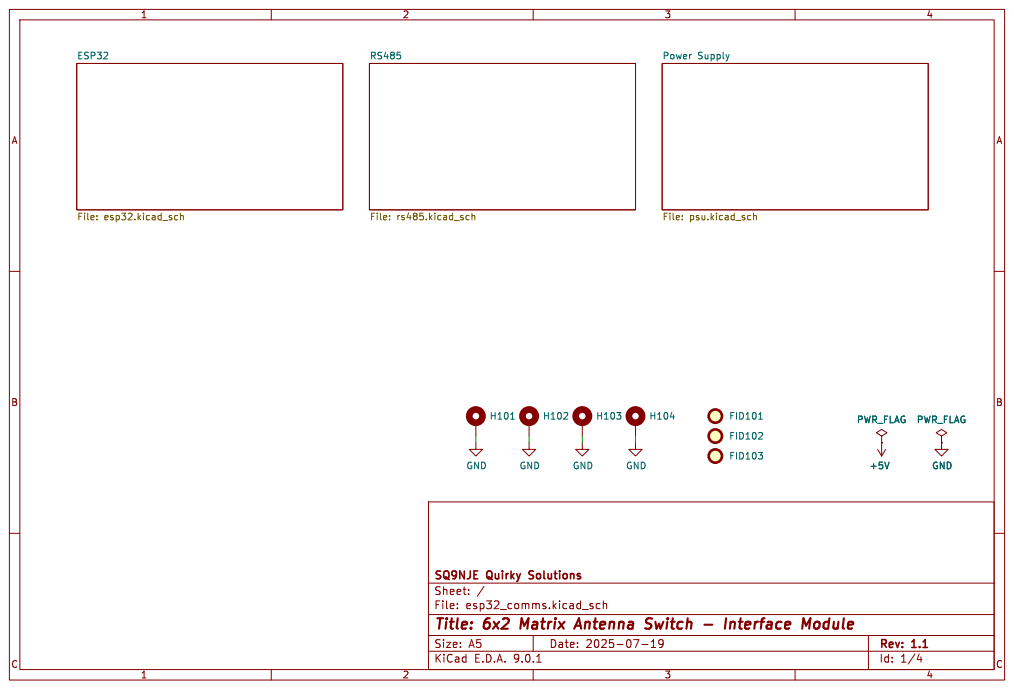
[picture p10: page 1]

SQ9NJE Quirky Solutions
Sheet: /
File: esp32_comms.kicad_sch
Title: 6x2 Matrix Antenna Switch - Interface Module

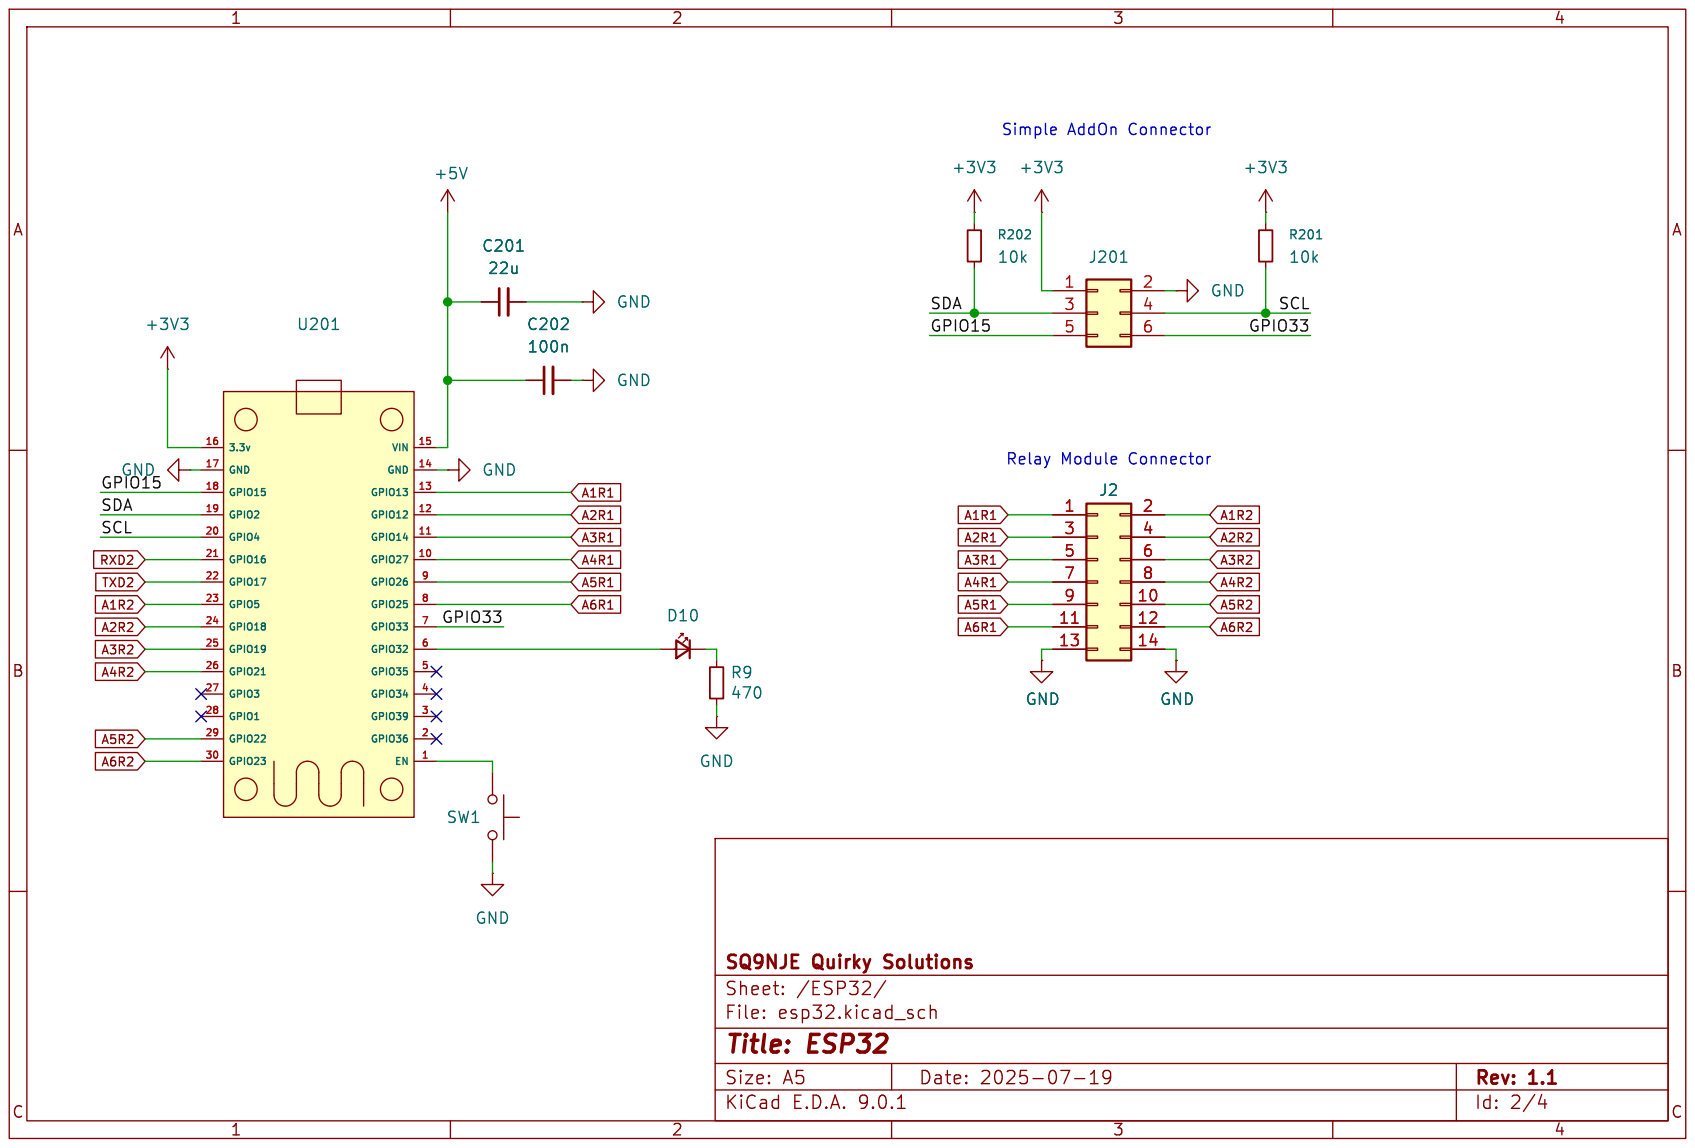
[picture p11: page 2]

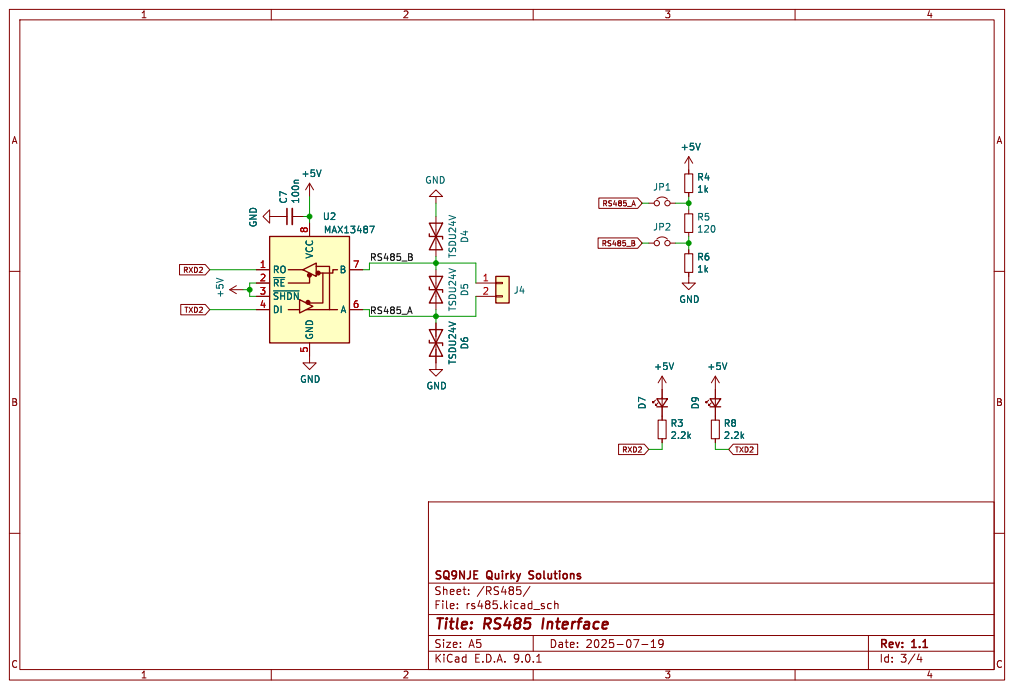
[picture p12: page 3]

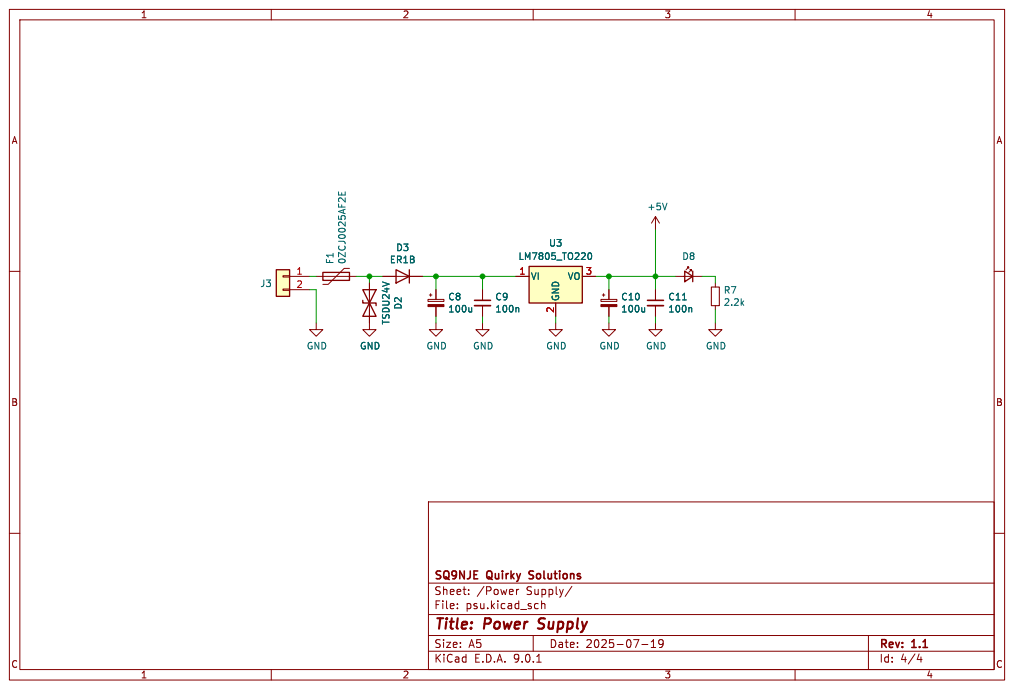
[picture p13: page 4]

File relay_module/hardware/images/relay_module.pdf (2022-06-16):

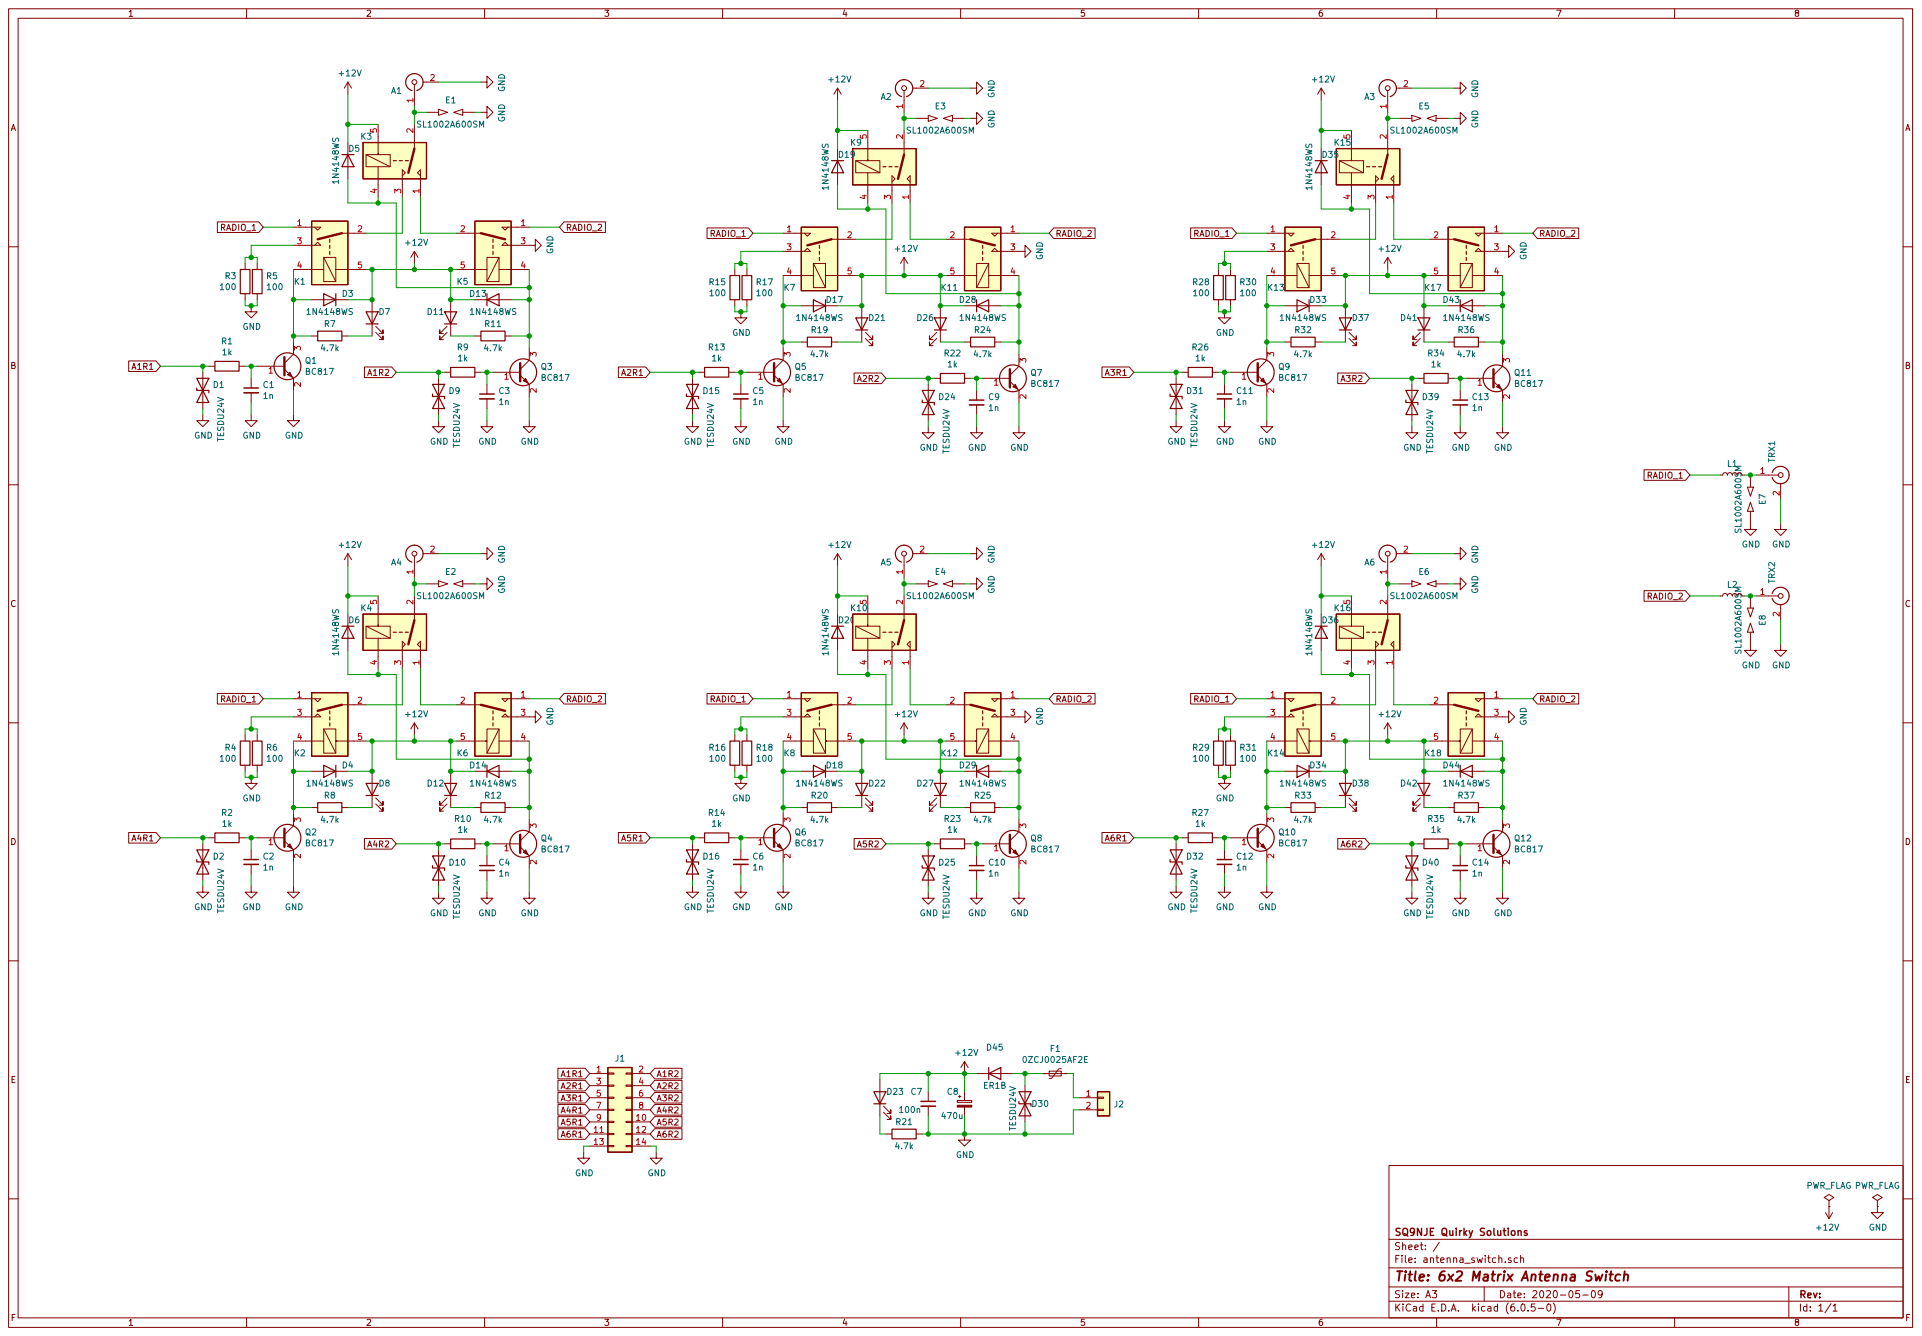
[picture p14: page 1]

File: antenna_switch.sch Sheet: / SQ9NJE Quirky Solutions R35

Id: 1/1 Title: 6x2 Matrix Antenna Switch

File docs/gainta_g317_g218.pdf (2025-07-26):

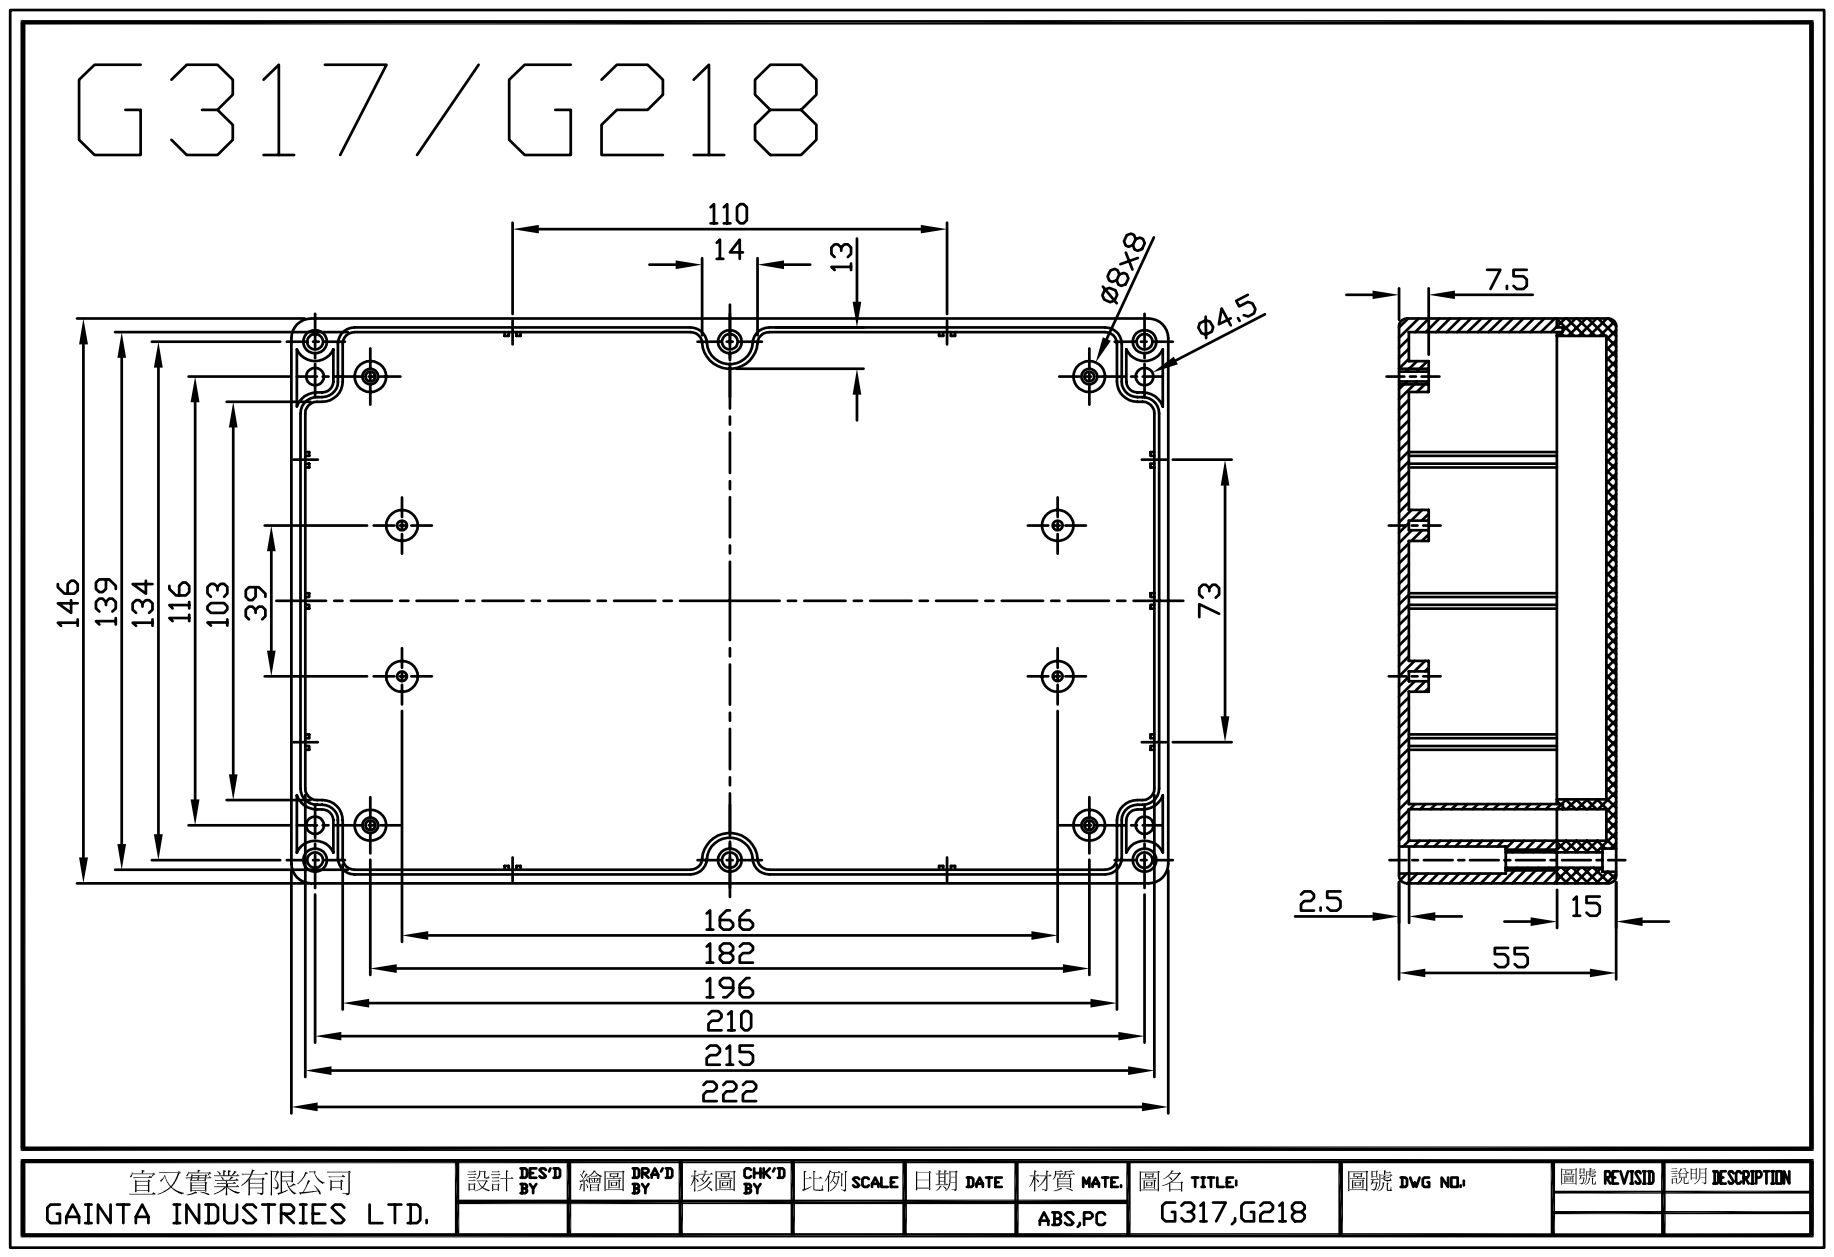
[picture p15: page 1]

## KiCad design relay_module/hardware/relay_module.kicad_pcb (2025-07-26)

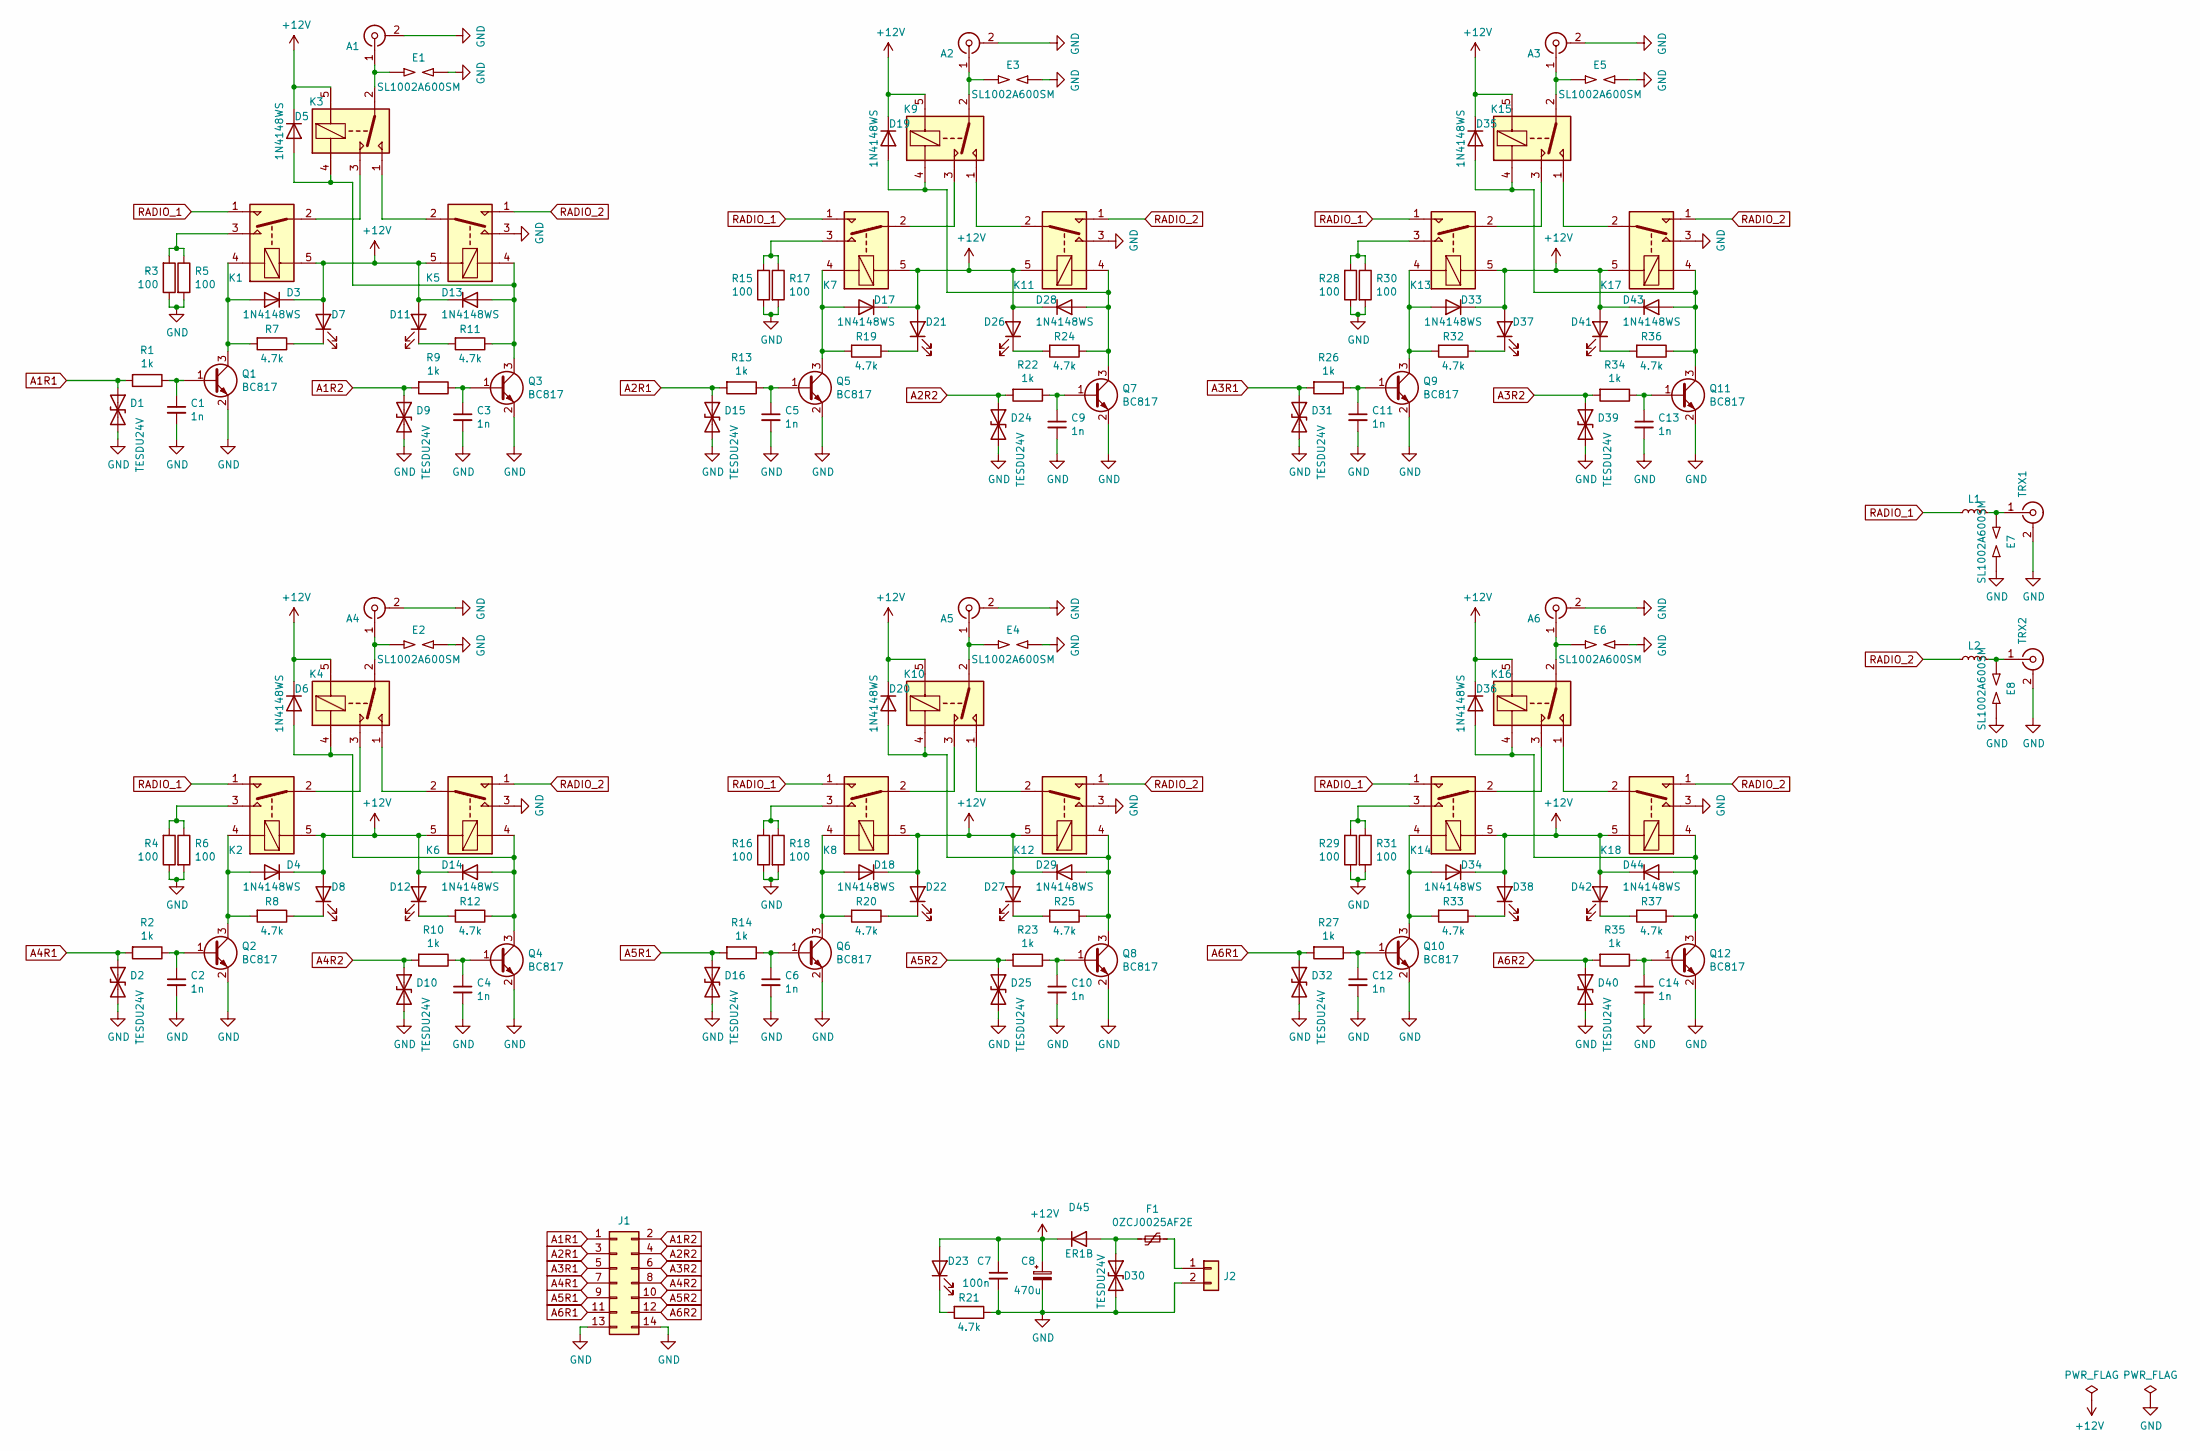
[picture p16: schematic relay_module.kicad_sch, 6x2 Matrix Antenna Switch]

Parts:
A1, A2, A3, A4, A5, A6: Conn_Coaxial; UC1-Square-2HolesRight
C1, C2, C3, C4, C5, C6, C9, C10, C11, C12, C13, C14: 1n; C_0805_2012Metric_Pad1.15x1.40mm_HandSolder
C7: 100n; C_0805_2012Metric_Pad1.15x1.40mm_HandSolder
C8: 470u; CP_Radial_D8.0mm_P3.50mm
D1, D2, D9, D10, D15, D16, D24, D25, D30, D31, D32, D39, D40: TESDU24V; R_0603_1608Metric_Pad1.05x0.95mm_HandSolder
D3, D4, D5, D6, D13, D14, D17, D18, D19, D20, D28, D29, D33, D34, D35, D36, D43, D44: 1N4148WS; D_SOD-323
D7, D8, D11, D12, D21, D22, D23, D26, D27, D37, D38, D41, D42: LED; LED_0805_2012Metric_Pad1.15x1.40mm_HandSolder
D45: ER1B; D_SMA_Handsoldering
E1, E2, E3, E4, E5, E6, E7, E8: SL1002A600SM; GDT_SL1002A_HandSolder
F1: 0ZCJ0025AF2E; Fuse_1206_3216Metric_Pad1.42x1.75mm_HandSolder
J1: Conn_02x07_Odd_Even; IDC-Header_2x07_P2.54mm_Vertical
J2: Conn_01x02; TerminalBlock_bornier-2_P5.08mm
K1, K2, K3, K4, K5, K6, K7, K8, K9, K10, K11, K12, K13, K14, K15, K16, K17, K18: Fujitsu_FTR-K1C; Relay_DPDT_Fujitsu_FTR-K1C
L1, L2: L_Small; R_Axial_DIN0411_L9.9mm_D3.6mm_P12.70mm_Horizontal
Q1, Q2, Q3, Q4, Q5, Q6, Q7, Q8, Q9, Q10, Q11, Q12: BC817; SOT-23
R1, R2, R9, R10, R13, R14, R22, R23, R26, R27, R34, R35: 1k; R_0805_2012Metric_Pad1.15x1.40mm_HandSolder
R3, R4, R5, R6, R15, R16, R17, R18, R28, R29, R30, R31: 100; R_2512_6332Metric_Pad1.52x3.35mm_HandSolder
R7, R8, R11, R12, R19, R20, R21, R24, R25, R32, R33, R36, R37: 4.7k; R_0805_2012Metric_Pad1.15x1.40mm_HandSolder
TRX1, TRX2: Conn_Coaxial; UC1-Square-2HolesRight

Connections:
+12V: C7.1, C8.1, D3.1 (K), D4.1 (K), D5.1 (K), D6.1 (K), D7.2 (A), D8.2 (A), D11.2 (A), D12.2 (A), D13.1 (K), D14.1 (K), D17.1 (K), D18.1 (K), D19.1 (K), D20.1 (K), D21.2 (A), D22.2 (A), D23.2 (A), D26.2 (A), D27.2 (A), D28.1 (K), D29.1 (K), D33.1 (K), D34.1 (K), D35.1 (K), D36.1 (K), D37.2 (A), D38.2 (A), D41.2 (A), D42.2 (A), D43.1 (K), D44.1 (K), D45.1 (K), K1.5, K2.5, K3.5, K4.5, K5.5, K6.5, K7.5, K8.5, K9.5, K10.5, K11.5, K12.5, K13.5, K14.5, K15.5, K16.5, K17.5, K18.5
A1R1: D1.1 (A1), J1.1, R1.2
A1R2: D9.1 (A1), J1.2, R9.2
A2R1: D15.1 (A1), J1.3, R13.2
A2R2: D24.1 (A1), J1.4, R22.2
A3R1: D31.1 (A1), J1.5, R26.2
A3R2: D39.1 (A1), J1.6, R34.2
A4R1: D2.1 (A1), J1.7, R2.2
A4R2: D10.1 (A1), J1.8, R10.2
A5R1: D16.1 (A1), J1.9, R14.2
A5R2: D25.1 (A1), J1.10, R23.2
A6R1: D32.1 (A1), J1.11, R27.2
A6R2: D40.1 (A1), J1.12, R35.2
GND: A1.2 (Ext), A2.2 (Ext), A3.2 (Ext), A4.2 (Ext), A5.2 (Ext), A6.2 (Ext), C1.2, C2.2, C3.2, C4.2, C5.2, C6.2, C7.2, C8.2, C9.2, C10.2, C11.2, C12.2, C13.2, C14.2, D1.2 (A2), D2.2 (A2), D9.2 (A2), D10.2 (A2), D15.2 (A2), D16.2 (A2), D24.2 (A2), D25.2 (A2), D30.2 (A2), D31.2 (A2), D32.2 (A2), D39.2 (A2), D40.2 (A2), E1.2, E2.2, E3.2, E4.2, E5.2, E6.2, E7.2, E8.2, J1.13, J1.14, J2.2, K5.3, K6.3, K11.3, K12.3, K17.3, K18.3, Q1.2 (E), Q2.2 (E), Q3.2 (E), Q4.2 (E), Q5.2 (E), Q6.2 (E), Q7.2 (E), Q8.2 (E), Q9.2 (E), Q10.2 (E), Q11.2 (E), Q12.2 (E), R3.1, R4.1, R5.2, R6.2, R15.1, R16.1, R17.2, R18.2, R21.1, R28.1, R29.1, R30.2, R31.2, TRX1.2 (Ext), TRX2.2 (Ext)
unnamed: A1.1 (In), E1.1, K3.2
unnamed: A2.1 (In), E3.1, K9.2
unnamed: A3.1 (In), E5.1, K15.2
unnamed: A4.1 (In), E2.1, K4.2
unnamed: A5.1 (In), E4.1, K10.2
unnamed: A6.1 (In), E6.1, K16.2
unnamed: C1.1, Q1.1 (B), R1.1
unnamed: C2.1, Q2.1 (B), R2.1
unnamed: C3.1, Q3.1 (B), R9.1
unnamed: C4.1, Q4.1 (B), R10.1
unnamed: C5.1, Q5.1 (B), R13.1
unnamed: C6.1, Q6.1 (B), R14.1
unnamed: C9.1, Q7.1 (B), R22.1
unnamed: C10.1, Q8.1 (B), R23.1
unnamed: C11.1, Q9.1 (B), R26.1
unnamed: C12.1, Q10.1 (B), R27.1
unnamed: C13.1, Q11.1 (B), R34.1
unnamed: C14.1, Q12.1 (B), R35.1
unnamed: D3.2 (A), K1.4, Q1.3 (C), R7.2
unnamed: D4.2 (A), K2.4, Q2.3 (C), R8.2
unnamed: D7.1 (K), R7.1
unnamed: D8.1 (K), R8.1
unnamed: D11.1 (K), R11.2
unnamed: D12.1 (K), R12.2
unnamed: D5.2 (A), D13.2 (A), K3.4, K5.4, Q3.3 (C), R11.1
unnamed: D6.2 (A), D14.2 (A), K4.4, K6.4, Q4.3 (C), R12.1
unnamed: D17.2 (A), K7.4, Q5.3 (C), R19.2
unnamed: D18.2 (A), K8.4, Q6.3 (C), R20.2
unnamed: D19.2 (A), D28.2 (A), K9.4, K11.4, Q7.3 (C), R24.1
unnamed: D20.2 (A), D29.2 (A), K10.4, K12.4, Q8.3 (C), R25.1
unnamed: D21.1 (K), R19.1
unnamed: D22.1 (K), R20.1
unnamed: D23.1 (K), R21.2
unnamed: D26.1 (K), R24.2
unnamed: D27.1 (K), R25.2
unnamed: D30.1 (A1), D45.2 (A), F1.2
unnamed: D33.2 (A), K13.4, Q9.3 (C), R32.2
unnamed: D34.2 (A), K14.4, Q10.3 (C), R33.2
unnamed: D35.2 (A), D43.2 (A), K15.4, K17.4, Q11.3 (C), R36.1
unnamed: D36.2 (A), D44.2 (A), K16.4, K18.4, Q12.3 (C), R37.1
unnamed: D37.1 (K), R32.1
unnamed: D38.1 (K), R33.1
unnamed: D41.1 (K), R36.2
unnamed: D42.1 (K), R37.2
unnamed: E7.1, L1.2, TRX1.1 (In)
unnamed: E8.1, L2.2, TRX2.1 (In)
unnamed: F1.1, J2.1
unnamed: K1.2, K3.3
unnamed: K1.3, R3.2, R5.1
unnamed: K2.2, K4.3
unnamed: K2.3, R4.2, R6.1
unnamed: K3.1, K5.2
unnamed: K4.1, K6.2
unnamed: K7.2, K9.3
unnamed: K7.3, R15.2, R17.1
unnamed: K8.3, R16.2, R18.1
unnamed: K10.1, K12.2
unnamed: K8.2, K10.3
unnamed: K9.1, K11.2
unnamed: K13.2, K15.3
unnamed: K13.3, R28.2, R30.1
unnamed: K14.2, K16.3
unnamed: K14.3, R29.2, R31.1
unnamed: K15.1, K17.2
unnamed: K16.1, K18.2
RADIO_1: K1.1, K2.1, K7.1, K8.1, K13.1, K14.1, L1.1
RADIO_2: K5.1, K6.1, K11.1, K12.1, K17.1, K18.1, L2.1

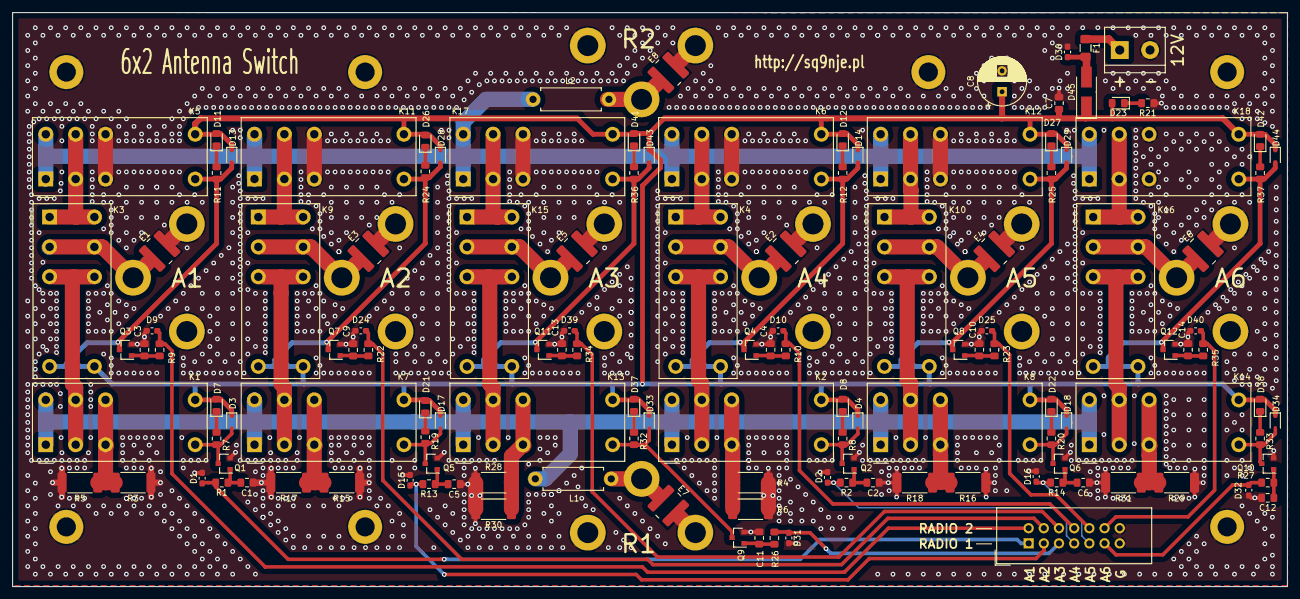
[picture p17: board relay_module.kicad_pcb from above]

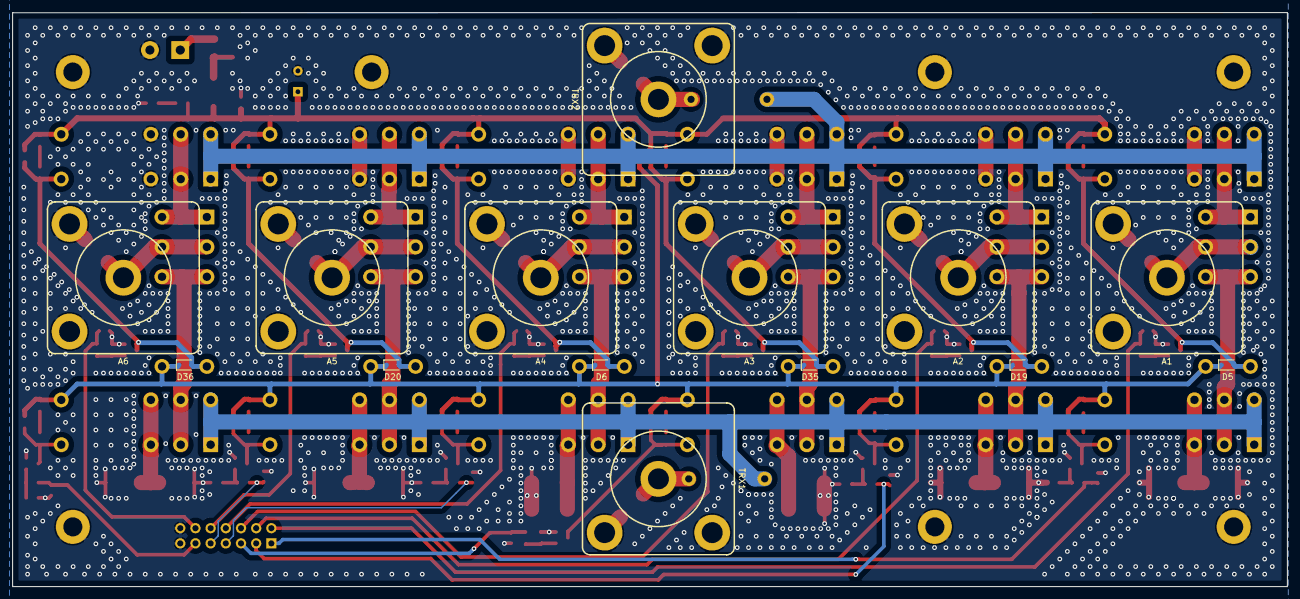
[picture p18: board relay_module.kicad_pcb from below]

Board: 2 copper layers, 213.3 x 96.0 mm, 147 parts (14 on the bottom side), 81 nets.

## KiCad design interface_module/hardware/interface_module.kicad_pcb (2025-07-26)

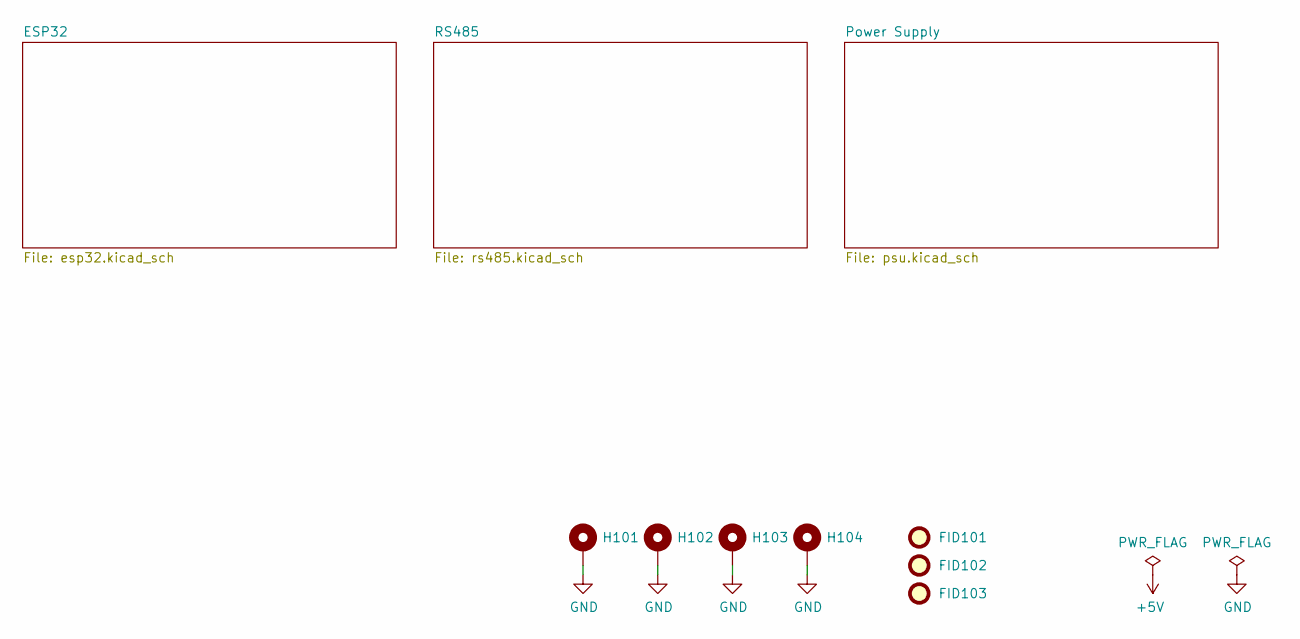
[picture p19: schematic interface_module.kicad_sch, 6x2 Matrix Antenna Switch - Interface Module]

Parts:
FID101, FID102, FID103: Fiducial; Fiducial_1mm_Mask2mm
H101, H102, H103, H104: MountingHole_Pad; MountingHole_3.2mm_M3_ISO7380_Pad

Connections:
GND: H101.1, H102.1, H103.1, H104.1; also elsewhere on the board

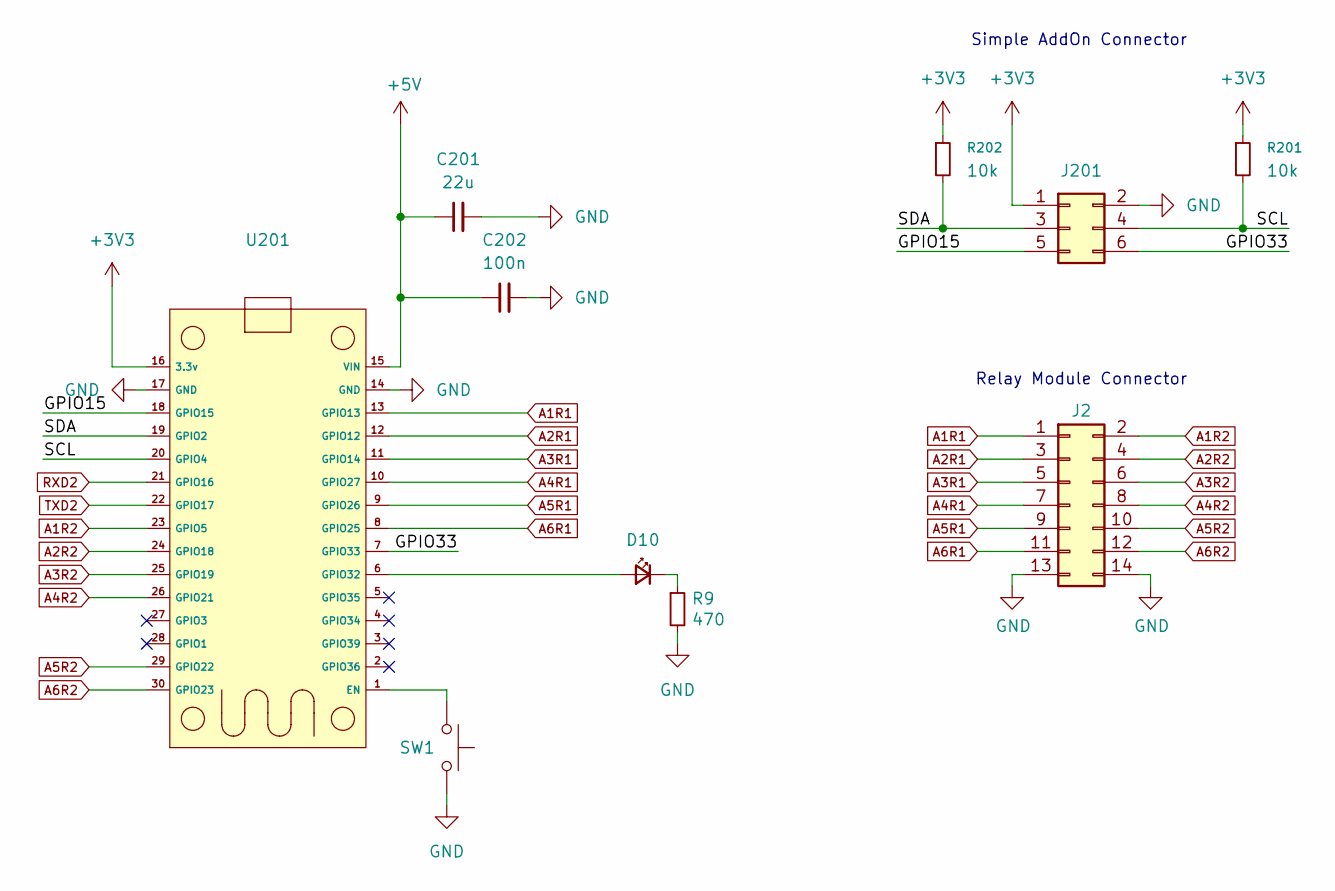
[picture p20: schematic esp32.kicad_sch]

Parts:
C201: 22u; C_1206_3216Metric_Pad1.33x1.80mm_HandSolder; LCSC Part # C12891
C202: 100n; C_0805_2012Metric_Pad1.15x1.40mm_HandSolder; LCSC Part # C49678
D10: LED_Small; LED_0805_2012Metric_Pad1.15x1.40mm_HandSolder; LCSC Part # C2297
J2: Conn_02x07_Odd_Even; IDC-Header_2x07_P2.54mm_Vertical
J201: Conn_02x03; PinHeader_2x03_P2.54mm_Vertical; Part Number LL1009-2A, 2.54MM 2*3PIN HEADER,LENGTH=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
R9: 470; R_0805_2012Metric_Pad1.20x1.40mm_HandSolder; LCSC Part # C17710
R201, R202: 10k; R_0805_2012Metric_Pad1.20x1.40mm_HandSolder; LCSC Part # C17414
SW1: SW_Push; SW_SPST_CK_RS282G05A3
U201: esp32_devkit_v1_doit

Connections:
+3V3: J201.1 (+12V), R201.1, R202.1, U201.16 (3.3v)
+5V: C201.1, C202.1, U201.15 (VIN); also elsewhere on the board
/ESP32/GPIO15: J201.5 (GND), U201.18 (GPIO15)
/ESP32/GPIO33: J201.6 (GND), U201.7 (GPIO33)
/ESP32/SCL: J201.4 (GND), R201.2, U201.20 (GPIO4)
/ESP32/SDA: J201.3 (GND), R202.2, U201.19 (GPIO2)
A1R1: J2.1, U201.13 (GPIO13)
A1R2: J2.2, U201.23 (GPIO5)
A2R1: J2.3, U201.12 (GPIO12)
A2R2: J2.4, U201.24 (GPIO18)
A3R1: J2.5, U201.11 (GPIO14)
A3R2: J2.6, U201.25 (GPIO19)
A4R1: J2.7, U201.10 (GPIO27)
A4R2: J2.8, U201.26 (GPIO21)
A5R1: J2.9, U201.9 (GPIO26)
A5R2: J2.10, U201.29 (GPIO22)
A6R1: J2.11, U201.8 (GPIO25)
A6R2: J2.12, U201.30 (GPIO23)
GND: C201.2, C202.2, J2.13, J2.14, J201.2 (+12V), R9.2, SW1.1, U201.14 (GND), U201.17 (GND); also elsewhere on the board
unnamed: D10.2 (A), U201.6 (GPIO32)
unnamed: D10.1 (K), R9.1
unnamed: SW1.2, U201.1 (EN)
RXD2: U201.21 (GPIO16); also elsewhere on the board
TXD2: U201.22 (GPIO17); also elsewhere on the board

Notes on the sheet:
Simple AddOn Connector
Relay Module Connector

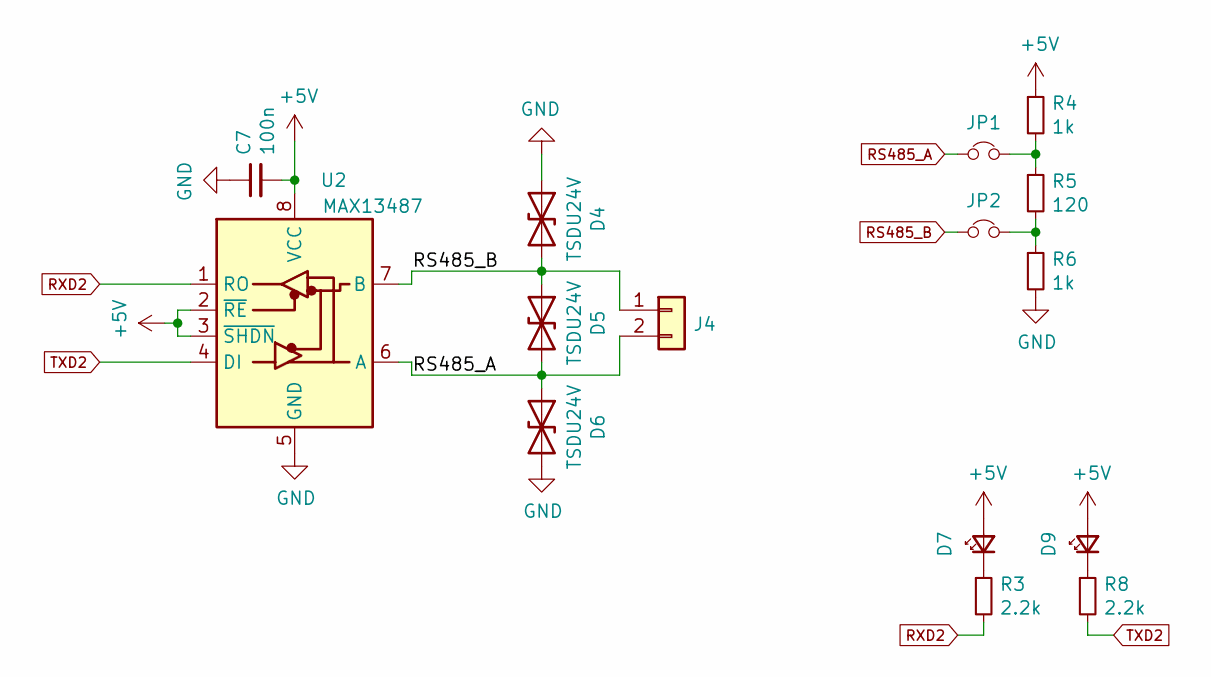
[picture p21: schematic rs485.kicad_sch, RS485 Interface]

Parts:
C7: 100n; C_0805_2012Metric_Pad1.15x1.40mm_HandSolder; LCSC Part # C49678
D4, D5, D6: TSDU24V; R_0603_1608Metric_Pad1.05x0.95mm_HandSolder; LCSC Part # C2836324
D7, D9: LED_Small; LED_0805_2012Metric_Pad1.15x1.40mm_HandSolder; LCSC Part # C2297
J4: Conn_01x02; TerminalBlock_bornier-2_P5.08mm
JP1, JP2: Jumper_NC_Small; SolderJumper-2_P1.3mm_Bridged_RoundedPad1.0x1.5mm
R3, R8: 2.2k; R_0805_2012Metric_Pad1.15x1.40mm_HandSolder; LCSC Part # C17520
R4, R6: 1k; R_0805_2012Metric_Pad1.15x1.40mm_HandSolder; LCSC Part # C17513
R5: 120; R_0805_2012Metric_Pad1.15x1.40mm_HandSolder; LCSC Part # C17437
U2: MAX13487; SOIC-8_3.9x4.9mm_P1.27mm; LCSC Part # C18347

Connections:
+5V: C7.2, D7.2 (A), D9.2 (A), R4.1, U2.2 (~RE), U2.3 (~SHDN), U2.8 (VCC); also elsewhere on the board
GND: C7.1, D4.1 (A1), D6.2 (A2), R6.2, U2.5 (GND); also elsewhere on the board
unnamed: D7.1 (K), R3.1
unnamed: D9.1 (K), R8.1
unnamed: JP1.2, R4.2, R5.1
unnamed: JP2.2, R5.2, R6.1
RS485_A: D5.2 (A2), D6.1 (A1), J4.2, JP1.1, U2.6 (A)
RS485_B: D4.2 (A2), D5.1 (A1), J4.1, JP2.1, U2.7 (B)
RXD2: R3.2, U2.1 (RO); also elsewhere on the board
TXD2: R8.2, U2.4 (DI); also elsewhere on the board

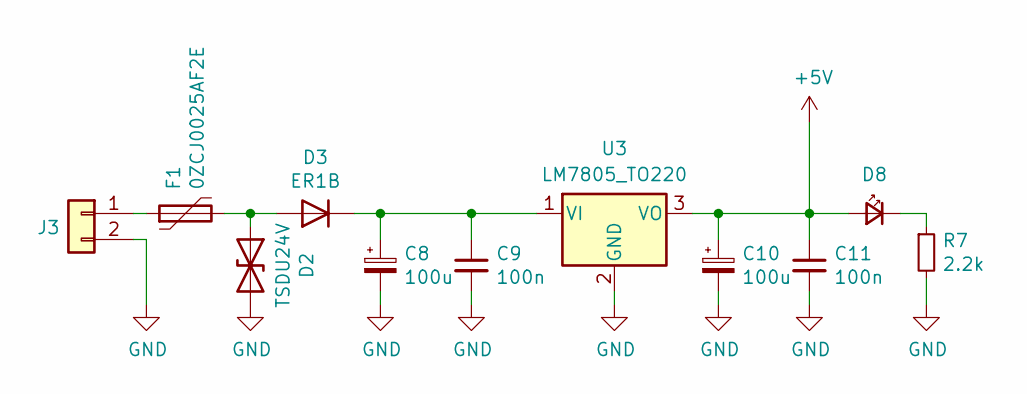
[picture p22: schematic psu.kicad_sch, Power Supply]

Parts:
C8, C10: 100u; CP_Radial_D8.0mm_P3.80mm
C9, C11: 100n; C_0805_2012Metric_Pad1.15x1.40mm_HandSolder; LCSC Part # C49678
D2: TSDU24V; R_0603_1608Metric_Pad1.05x0.95mm_HandSolder; LCSC Part # C2836324
D3: ER1B; D_SMA; LCSC Part # C2480
D8: LED_Small; LED_0805_2012Metric_Pad1.15x1.40mm_HandSolder; LCSC Part # C2297
F1: 0ZCJ0025AF2E; Fuse_1206_3216Metric_Pad1.42x1.75mm_HandSolder; LCSC Part # C269104
J3: Conn_01x02; TerminalBlock_bornier-2_P5.08mm
R7: 2.2k; R_0805_2012Metric_Pad1.15x1.40mm_HandSolder; LCSC Part # C17520
U3: LM7805_TO220; TO-220-3_Horizontal_TabDown

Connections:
+5V: C10.1, C11.1, D8.2 (A), U3.3 (VO); also elsewhere on the board
GND: C8.2, C9.2, C10.2, C11.2, D2.2 (A2), J3.2, R7.2, U3.2 (GND); also elsewhere on the board
unnamed: D2.1 (A1), D3.2 (A), F1.2
unnamed: C8.1, C9.1, D3.1 (K), U3.1 (VI)
unnamed: D8.1 (K), R7.1
unnamed: F1.1, J3.1

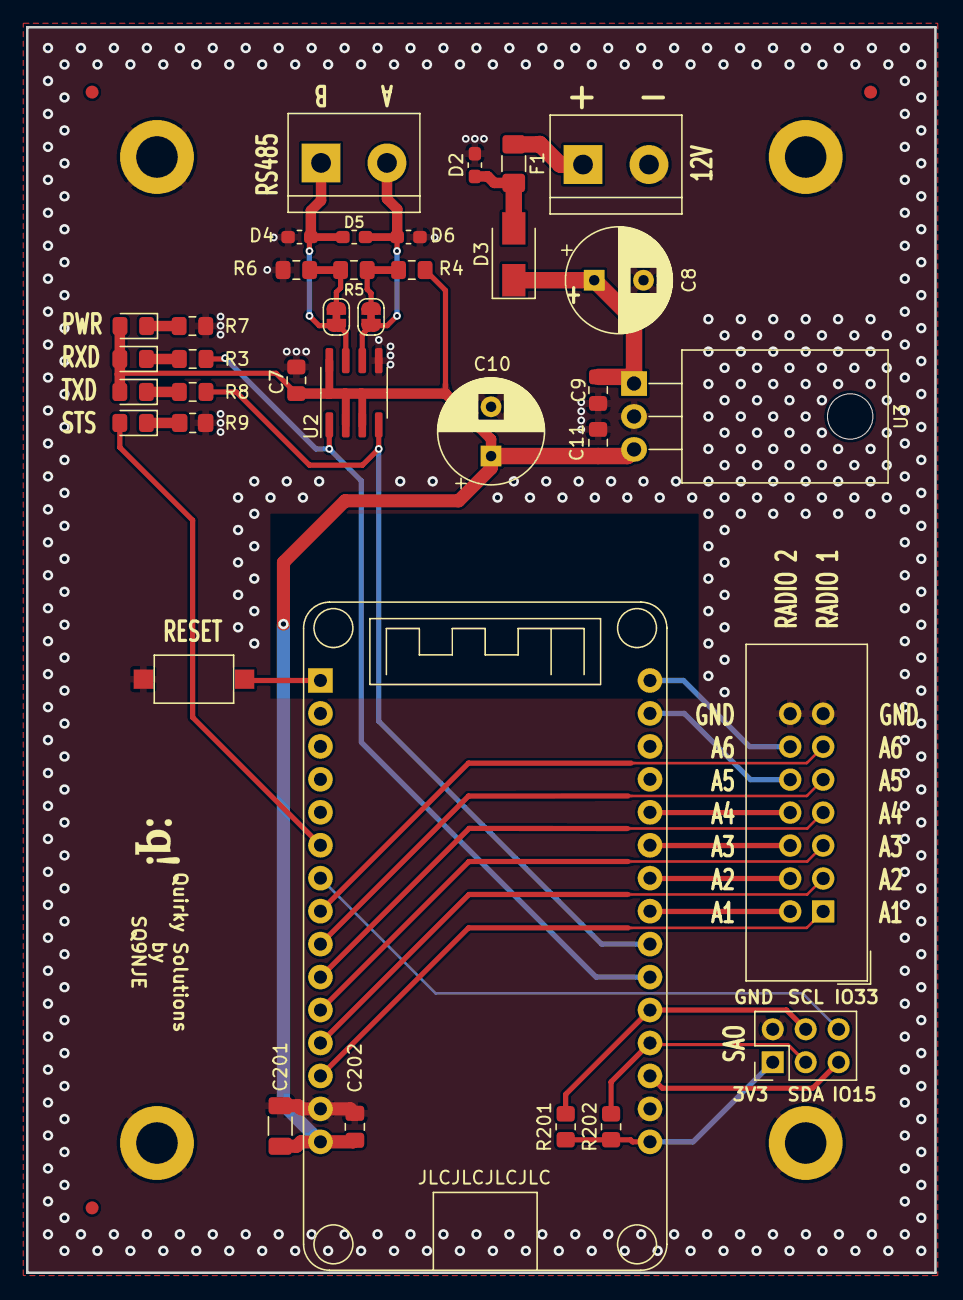
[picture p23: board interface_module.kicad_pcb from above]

Board: 2 copper layers, 70.0 x 96.0 mm, 44 parts (0 on the bottom side), 34 nets.

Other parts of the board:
Ref**: Val**; qs_logo

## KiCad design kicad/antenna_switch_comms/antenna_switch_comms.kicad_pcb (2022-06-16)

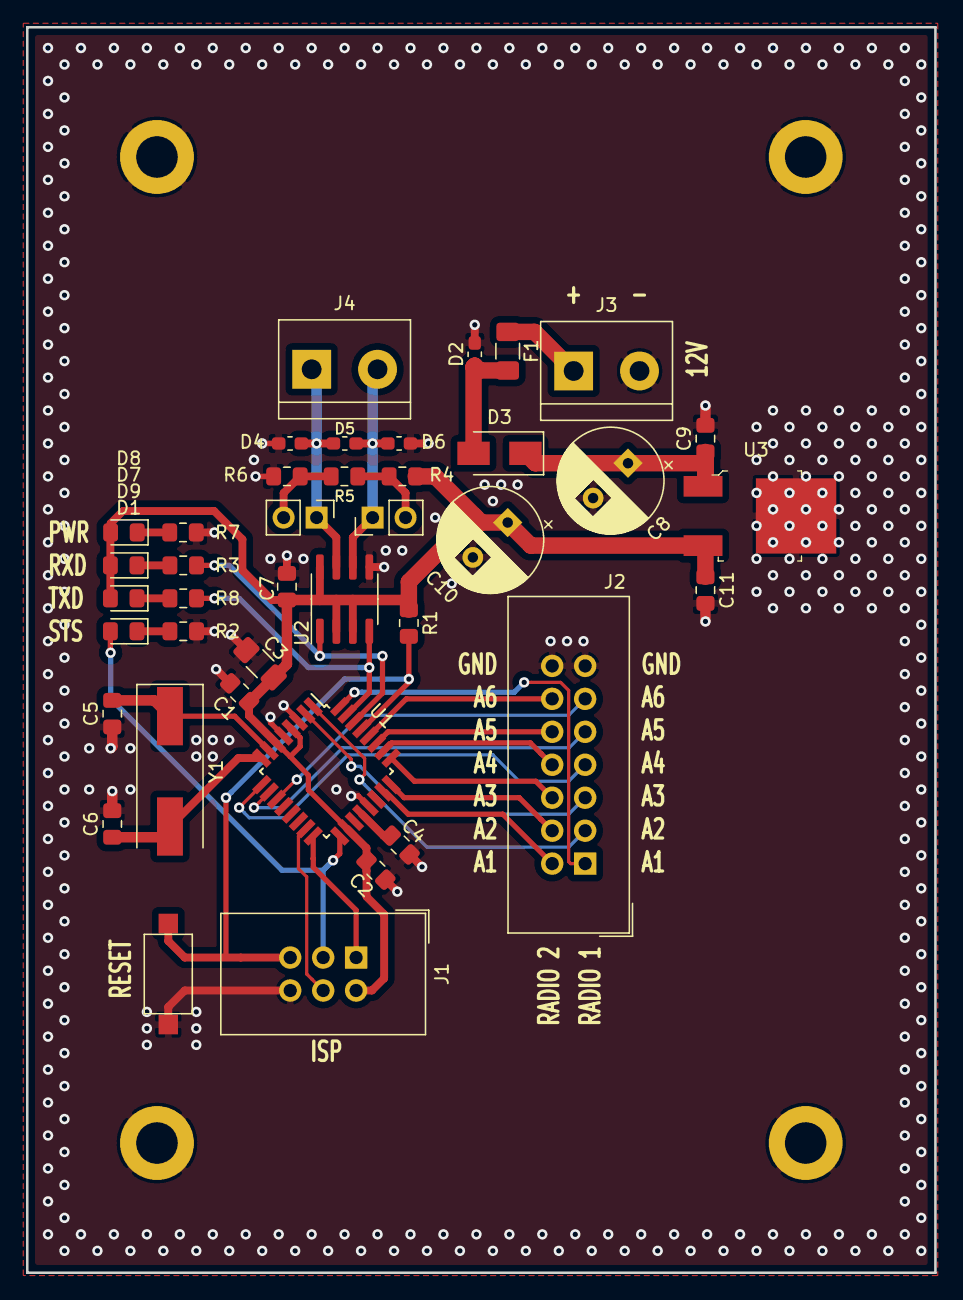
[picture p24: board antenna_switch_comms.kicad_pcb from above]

Board: 2 copper layers, 70.0 x 96.0 mm, 40 parts (0 on the bottom side), 34 nets.

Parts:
C1, C2, C4, C7, C9, C11: 100n; C_0805_2012Metric_Pad1.15x1.40mm_HandSolder
C3: 4.7u; C_1206_3216Metric_Pad1.42x1.75mm_HandSolder
C5, C6: 18p; C_0805_2012Metric_Pad1.15x1.40mm_HandSolder
C8, C10: 100u; CP_Radial_D8.0mm_P3.80mm
D1, D7, D8, D9: LED_Small; LED_0805_2012Metric_Pad1.15x1.40mm_HandSolder
D2, D4, D5, D6: TESDU24V; R_0603_1608Metric_Pad1.05x0.95mm_HandSolder
D3: ER1B; D_SMA
F1: 0ZCJ0025AF2E; Fuse_1206_3216Metric_Pad1.42x1.75mm_HandSolder
J1: AVR-ISP-6; IDC-Header_2x03_P2.54mm_Vertical
J2: Conn_02x07_Odd_Even; IDC-Header_2x07_P2.54mm_Vertical
J3, J4: Conn_01x02; TerminalBlock_bornier-2_P5.08mm
JP1, JP2: Jumper_NC_Small; PinHeader_1x02_P2.54mm_Vertical
R1, R4, R6: 1k; R_0805_2012Metric_Pad1.15x1.40mm_HandSolder
R2, R3, R7, R8: 2.2k; R_0805_2012Metric_Pad1.15x1.40mm_HandSolder
R5: 120; R_0805_2012Metric_Pad1.15x1.40mm_HandSolder
SW1: SW_Push; SW_SPST_CK_RS282G05A3
U1: ATmega328P-AU; TQFP-32_7x7mm_P0.8mm
U2: MAX13487; SOIC-8_3.9x4.9mm_P1.27mm
U3: MC7805BDTRKG; TO-252-3
Y1: 16M; Crystal_SMD_HC49-SD

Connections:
+5V: C1.1, C2.1, C3.1, C7.2, C10.1, C11.1, D7.2, D8.2, D9.2, J1.2, R1.1, R4.1, U1.4, U1.6, U1.18, U2.2, U2.3, U2.8, U3.3
A1R1: J2.1, U1.32
A1R2: J2.2, U1.23
A2R1: J2.3, U1.1
A2R2: J2.4, U1.24
A3R1: J2.5, U1.2
A3R2: J2.6, U1.25
A4R1: J2.7, U1.9
A4R2: J2.8, U1.26
A5R1: J2.9, U1.10
A5R2: J2.10, U1.27
A6R1: J2.11, U1.11
A6R2: J2.12, U1.28
GND: C1.2, C2.2, C3.2, C4.1, C5.1, C6.1, C7.1, C8.2, C9.2, C10.2, C11.2, D2.2, D4.1, D6.2, J1.6, J2.13, J2.14, J3.2, R2.2, R6.2, R7.2, SW1.1, U1.3, U1.5, U1.21, U2.5, U3.4
MISO: J1.1, U1.16
MOSI: J1.4, U1.15
unnamed: C4.2, U1.20
unnamed: C5.2, U1.7, Y1.1
unnamed: C6.2, U1.8, Y1.2
unnamed: C8.1, C9.1, D3.1, U3.1
unnamed: D1.1, R2.1
unnamed: D2.1, D3.2, F1.2
unnamed: D7.1, R3.1
unnamed: D8.1, R7.1
unnamed: D9.1, R8.1
unnamed: F1.1, J3.1
unnamed: JP1.2, R4.2, R5.1
unnamed: JP2.2, R5.2, R6.1
RESET: J1.5, R1.2, SW1.2, U1.29
RS485_A: D5.2, D6.1, J4.2, JP1.1, U2.6
RS485_B: D4.2, D5.1, J4.1, JP2.1, U2.7
RXD: R3.2, U1.30, U2.1
SCK: D1.2, J1.3, U1.17
TXD: R8.2, U1.31, U2.4

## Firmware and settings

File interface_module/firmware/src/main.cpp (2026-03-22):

#include <Arduino.h>
#include <WiFi.h>
#include <WiFiManager.h>
#include <ESPAsyncWebServer.h>
#include <WebSocketsServer.h>
#include <ArduinoJson.h>
#include <SPIFFS.h>
#include <ESPmDNS.h>
#include <ArduinoOTA.h>

// Project includes
#include "globals.h"
#include "antenna_hardware.h"
#include "websocket.h"
#include "command_parser.h"
#include "storage.h"
#include "web_server.h"
#include "wifi_manager.h"
#include "otrsp.h"

void initializeOTA() {
  ArduinoOTA.setHostname(mdnsHostname.c_str());
  ArduinoOTA.setPassword("antenna123");  // Set OTA password for security
  
  ArduinoOTA.onStart([]() {
    String type;
    if (ArduinoOTA.getCommand() == U_FLASH) {
      type = "sketch";
    } else { // U_SPIFFS
      type = "filesystem";
      SPIFFS.end();
    }
    Serial.println("Start updating " + type);
    
    // Turn off all relays during OTA
    for(uint8_t radio = 0; radio < 2; radio++) {
      for(uint8_t antenna = 0; antenna < 6; antenna++) {
        digitalWrite(relay[radio][antenna], LOW);
      }
    }
    currentAntenna[0] = 0;
    currentAntenna[1] = 0;
    
    // Notify connected clients
    sendOTAStatus("starting", type, 0);
  });
  
  ArduinoOTA.onEnd([]() {
    Serial.println("\nOTA Update complete");
    sendOTAStatus("complete", "", 100);
    delay(1000);
  });
  
  ArduinoOTA.onProgress([](unsigned int progress, unsigned int total) {
    unsigned int percent = (progress / (total / 100));
    Serial.printf("Progress: %u%%\r", percent);
    sendOTAStatus("progress", "", percent);
  });
  
  ArduinoOTA.onError([](ota_error_t error) {
    Serial.printf("Error[%u]: ", error);
    String errorMsg = "";
    if (error == OTA_AUTH_ERROR) {
      errorMsg = "Auth Failed";
      Serial.println("Auth Failed");
    } else if (error == OTA_BEGIN_ERROR) {
      errorMsg = "Begin Failed";
      Serial.println("Begin Failed");
    } else if (error == OTA_CONNECT_ERROR) {
      errorMsg = "Connect Failed";
      Serial.println("Connect Failed");
    } else if (error == OTA_RECEIVE_ERROR) {
      errorMsg = "Receive Failed";
      Serial.println("Receive Failed");
    } else if (error == OTA_END_ERROR) {
      errorMsg = "End Failed";
      Serial.println("End Failed");
    }
    sendOTAStatus("error", errorMsg, 0);
  });
  
  ArduinoOTA.begin();
  Serial.println("OTA Ready");
  Serial.print("OTA Password: antenna123");
  Serial.print("IP address: ");
  Serial.println(WiFi.localIP());
}

void setup() {
  Serial.begin(115200);
  Serial2.begin(9600, SERIAL_8N1, RXD2, TXD2);
  
  Serial.println("Starting 6x2 Antenna Switch SQ9NJE");

  // Initialize storage
  if(!initializeStorage()) {
    return;
  }

  // Initialize hardware
  initializeHardware();

  // Load settings
  loadSettings();

  // Initialize network
  initializeWiFi();
  initializeMDNS();

  // Initialize WebSocket server
  initializeWebSocket();

  // Initialize OTRSP
  initializeOTRSP();

  // Initialize OTA
  initializeOTA();

  // Initialize and start web server
  initializeWebServer();

  blink(3);
  Serial.println("System ready");
}

void loop() {
  ArduinoOTA.handle();
  webSocket.loop();
  
  // Handle OTRSP TCP + serial
  handleOTRSPLoop();

  // Handle UART0 (Serial) commands - debug output
  handleSerialInput(Serial, Serial);

  // Handle UART2 commands (only if not used for OTRSP)
  if (!otrspSerialEnabled) {
    handleSerialInput(Serial2, Serial);
  }
}

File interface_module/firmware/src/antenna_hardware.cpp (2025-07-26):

#include "antenna_hardware.h"
#include "globals.h"
#include "websocket.h"

void initializeHardware() {
  // Initialize all relay control pins as outputs
  for(uint8_t radio = 0; radio < 2; radio++) {
    for(uint8_t antenna = 0; antenna < 6; antenna++) {
      pinMode(relay[radio][antenna], OUTPUT);
      digitalWrite(relay[radio][antenna], LOW);
    }
  }
  
  // Initialize LED pins
  pinMode(STATUS_LED, OUTPUT);
  pinMode(BUILTIN_LED, OUTPUT);
}

void blink(uint8_t n) {
  for(uint8_t i = 0; i < n; i++) {
    digitalWrite(STATUS_LED, 1);
    delay(50);
    digitalWrite(STATUS_LED, 0);
    delay(50);  
  }
}

uint8_t selectAntenna(uint8_t radio, uint8_t antenna) {
  if(radio > 1 || antenna > 6) {
    blink(3);
    return 1;
  }
  
  // Single radio mode - always disconnect radio 2
  if(singleRadioMode && radio == 1) {
    if(currentAntenna[1] > 0) {
      digitalWrite(relay[1][currentAntenna[1]-1], 0);
      currentAntenna[1] = 0;
    }
    sendWebSocketUpdate();
    blink(1);
    return 0;
  }
  
  // Check if antenna is already selected by the other radio (unless disconnecting)
  if(antenna > 0) {
    uint8_t otherRadio = (radio == 0) ? 1 : 0;
    
    if(currentAntenna[otherRadio] == antenna) {
      // If antenna swapping is enabled, perform the swap
      if(antennaSwappingEnabled) {
        uint8_t previousAntenna = currentAntenna[radio];
        
        // Step 1: Disconnect the other radio
        digitalWrite(relay[otherRadio][antenna-1], 0);
        
        // Step 2: Connect the first radio to the desired antenna
        if(currentAntenna[radio] > 0) {
          digitalWrite(relay[radio][currentAntenna[radio]-1], 0);
        }
        digitalWrite(relay[radio][antenna-1], 1);
        currentAntenna[radio] = antenna;
        
        // Step 3: Connect the other radio to the antenna that was used by the first radio
        if(previousAntenna > 0 && !singleRadioMode) {
          digitalWrite(relay[otherRadio][previousAntenna-1], 1);
          currentAntenna[otherRadio] = previousAntenna;
        } else {
          currentAntenna[otherRadio] = 0;
        }
        
        sendWebSocketUpdate();
        blink(1);
        return 0;
      } else {
        // Antenna swapping disabled - return busy error
        blink(3);
        return 2;
      }
    }
  }
   
  // Turn off current antenna relay
  if(currentAntenna[radio] > 0)
    digitalWrite(relay[radio][currentAntenna[radio]-1], 0);
  
  // Turn on new antenna relay (if not disconnecting)
  if(antenna > 0) 
    digitalWrite(relay[radio][antenna-1], 1);
  
  currentAntenna[radio] = antenna;
  
  // Send WebSocket update
  sendWebSocketUpdate();
  
  blink(1);
  return 0;
}

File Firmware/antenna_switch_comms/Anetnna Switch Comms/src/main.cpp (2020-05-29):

#include <Arduino.h>
#include <avr/wdt.h>

#define BUF_SIZE   32

uint8_t currentAntenna[2];
const uint8_t relay[2][6] = {{2, 3, 4, 5, 6, 7}, {A0, A1, A2, A3, A4, A5}};

void blink(uint8_t n) {
  for( uint8_t i = 0; i < n; i++) {
    digitalWrite(13, 1);
    delay(50);
    digitalWrite(13, 0);
    delay(50);  
  }
}

uint8_t selectAntenna(uint8_t radio, uint8_t antenna) {
  if(radio > 1 || antenna > 6) {
    blink(3);
    return 1;
  }
  if(antenna > 0) {
    if(radio == 0) {
      if(currentAntenna[1] == antenna) {
        blink(3);
        return 2;
      }    
    }
    else {
      if(currentAntenna[0] == antenna) {
        blink(3);
        return 2;
      }
    }
  }
   
  if(currentAntenna[radio] > 0)
    digitalWrite(relay[radio][currentAntenna[radio]-1], 0);
  if(antenna > 0) 
    digitalWrite(relay[radio][antenna-1], 1);
  currentAntenna[radio] = antenna;
  
  blink(1);
  return 0;
}

void parseCommand(char* commandLine) {

  char* cmd = strsep(&commandLine, " ");
  
  if(strcmp(cmd, "blink") == 0) {
    int num = atoi(strsep(&commandLine, " "));
    blink(num);
  } 
  else if(strcmp(cmd, "set") == 0) {
    int r = atoi(strsep(&commandLine, " "));
    int a = atoi(strsep(&commandLine, " "));
    int result = selectAntenna(r-1, a);
    if(result == 0)
      Serial.println("+OK");
    else if(result == 1)
      Serial.println("!ERR");
    else if(result == 2)
      Serial.println("!BUSY");
  }
  else if(strcmp(cmd, "get") == 0) {
    int r = atoi(strsep(&commandLine, " "));
    Serial.println(currentAntenna[r-1]);
  }
  else if(strcmp(cmd, "?") == 0) {
    Serial.println("6x2 Antenna Switch SQ9NJE");
  }
  else if(strcmp(cmd, "test") == 0) {
    for(uint8_t r = 0; r < 2; r++)
      for(int8_t a = 6; a >= 0; a--) {
        selectAntenna(r, a);
        delay(100);
      }
  }
}

void setup() {
  wdt_enable(WDTO_1S);
  Serial.begin(9600);

  pinMode(A0, OUTPUT);
  pinMode(A1, OUTPUT);
  pinMode(A2, OUTPUT);
  pinMode(A3, OUTPUT);
  pinMode(A4, OUTPUT);
  pinMode(A5, OUTPUT);
  pinMode(2, OUTPUT);
  pinMode(3, OUTPUT);
  pinMode(4, OUTPUT);
  pinMode(5, OUTPUT);
  pinMode(6, OUTPUT);
  pinMode(7, OUTPUT);
  pinMode(13, OUTPUT);

  blink(3);
  Serial.println("Hello");
}

void loop() {
  wdt_reset();

  while(Serial.available()) {
    static char buffer[BUF_SIZE];
    static uint8_t len = 0;

    char data = Serial.read();
    if(data == '\r' || data == '\n') {
      buffer[len] = '\0';
      parseCommand(buffer);
      len = 0;
    }
    else if(len < BUF_SIZE-1)
      buffer[len++] = tolower(data);
  }

}

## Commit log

2019-09-29 Initial schematic
    [antenna_switch.kicad_pcb, antenna_switch.sch]
2019-09-29 Schematic libs
    [antenna_switch.sch]
2019-09-29 Compensation coils
    [antenna_switch.sch]
2020-05-09 Relays in series to increase isolation
    [antenna_switch.kicad_pcb, antenna_switch.sch]
2020-05-10 Initial PCB layout work
    [1550Z124.kicad_pcb, antenna_switch.sch]
2020-05-10 Some more layout
    [1550Z124.kicad_pcb, antenna_switch.sch]
2020-05-11 Some layout and routing
    [1550Z124.kicad_pcb]
2020-05-13 routing finished
    [1550Z124.kicad_pcb]
2020-05-13 top silk
    [1550Z124.kicad_pcb]
2020-05-14 top ground plane
    [1550Z124.kicad_pcb]
2020-05-14 bottom silk
    [1550Z124.kicad_pcb]
2020-05-14 vias, lots of vias
    [1550Z124.kicad_pcb]
2020-05-16 reverse protection diode
    [antenna_switch.kicad_pcb, antenna_switch.sch]
2020-05-16 less vias
    [antenna_switch.kicad_pcb]
2020-05-19 Comms module
    [antenna_switch-B_Cu.gbr, antenna_switch-B_Mask.gbr, antenna_switch-B_SilkS.gbr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]
2023-10-23 Add drilling template
    [drilling_template.dxf]
2023-10-23 KiCAD project
    [antenna_switch.kicad_sch]
2025-07-26 ESP32 Interface Module (#3)
    [esp32.kicad_sch, esp32_comms.kicad_pcb, esp32_comms.kicad_sch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]
2025-07-26 Rearrange files
    [G218_cover.3mf, User Library-G218-G317-REV-F.SLDPRT, User Library-G218-G317-REV-F.step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]
2025-09-09 Enclosure top
    [antenna_switch_enclosure_top.3mf, antenna_switch_enclosure_top.step]
2026-03-22 Fix relay pin assignment (#16)
2026-03-22 Display only antennas with a description (#17)
2026-03-22 Fix disabled button in swapping mode (#19)
